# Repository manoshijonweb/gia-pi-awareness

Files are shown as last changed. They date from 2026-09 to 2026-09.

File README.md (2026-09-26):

# Gia — hardware bring-up

Raspberry Pi 5 Model B Rev 1.0, Pi OS with Python 3.13.5, `aarch64`.

Hostname `pi` (**not** `raspberrypi` — `raspberrypi.local` will not resolve).

## How to set it up

The finished device is the app in [`PI_AWARENESS/`](PI_AWARENESS/). It is an offline
assistive device for blind users that announces objects, colours, text and distance by
voice, in English and Hindi.

You need a Raspberry Pi 5 running Raspberry Pi OS 64-bit, the wired hardware listed
below, and an internet connection for the first install only.

```bash
git clone https://github.com/manoshijonweb/gia-pi-awareness.git
cd gia-pi-awareness/PI_AWARENESS
bash install.sh
sudo reboot
```

After the reboot the device says **"I am ready"** and listens for commands.

**The AI models are not in this repository.** They are too large for GitHub.
`install.sh` downloads them once from their public sources. The YOLO26 and OCR files
are checked against pinned SHA-256 hashes. The Vosk models have no published hash, so
the installer records their hashes locally and checks against those afterwards.

| Model | Used for | Downloaded from |
|---|---|---|
| YOLO26 (ONNX) | Object detection | Hugging Face (`onnx-community`) |
| PP-OCRv5 (RapidOCR) | Reading text | ModelScope (`RapidAI`) |
| Vosk small en-in, small hi | English and Hindi voice commands | alphacephei.com |

To fetch or check them again later:

```bash
.venv/bin/python tools/download_models.py           # download anything missing
.venv/bin/python tools/download_models.py --verify  # check files, no internet
```

Once installed, the device never needs the internet. Full instructions, voice
commands and troubleshooting are in [`PI_AWARENESS/README.md`](PI_AWARENESS/README.md).

The rest of this page is the original hardware bring-up log.

## Hardware

| Part | Bus | Status |
|---|---|---|
| VL53L0X time-of-flight ranger | I2C, 0x29 | verified — model `0xEE`, rev `0x10` |
| INMP441 MEMS microphone | I2S capture | verified — speech transcribed back as text |
| MAX98357A class-D amp | I2S playback | verified — 440Hz tone audible |

### Wiring

Both audio parts share BCLK and LRCLK; only the data line differs.

| Pin (BCM) | Header | VL53L0X | INMP441 | MAX98357A |
|---|---|---|---|---|
| GPIO2 | 3 | SDA | — | — |
| GPIO3 | 5 | SCL | — | — |
| GPIO18 | 12 | — | SCK | BCLK |
| GPIO19 | 35 | — | WS | LRC |
| GPIO20 | 38 | — | SD | — |
| GPIO21 | 40 | — | — | DIN |
| 3V3 | 1 / 17 | VIN | VDD | — |
| 5V | 2 / 4 | — | — | VIN |
| GND | 6 / 9 / 39 | GND | GND, L/R | GND, GND |

Three details that are easy to get wrong:

- **INMP441 `L/R` to GND.** Selects the left slot. Floating gives silence.
- **MAX98357A `VIN` to 5V**, not 3.3V. 3.3V works but is very quiet.
- **MAX98357A `SD` left floating.** Averages L+R to mono.

VL53L0X `XSHUT` floats or goes high — never low, or the chip sits in reset and
the bus scans clean.

## Boot configuration

`/boot/firmware/config.txt` (note: `/boot/firmware/`, not `/boot/`, on Pi 5).

```
dtparam=i2c_arm=on

[all]
# Gia: INMP441 (capture) + MAX98357A (playback) on one I2S bus
dtoverlay=googlevoicehat-soundcard
```

Backup of the pre-change file: `/boot/firmware/config.txt.bak-gia`.

`googlevoicehat-soundcard` is the overlay to use despite the name — it is the
generic full-duplex I2S card, and it is what puts capture *and* playback on a
single card. `hifiberry-dac` would drive the MAX98357A but leave no microphone.

`dtoverlay=nospi10` under `[pi5]` is stock Pi OS. Leave it.

After reboot, `aplay -l` and `arecord -l` both show:

```
card 2: sndrpigooglevoi [snd_rpi_googlevoicehat_soundcar]
```

Cards 0 and 1 are the Pi 5's two HDMI outputs and are unrelated.

## Scripts

One file per device. Each is a small module with a single class, and each runs
on its own as a demo. Run one to test that device; import it to build on it.

| File | Class | What it does |
|---|---|---|
| `vl53l0x.py` | `Ranger` | Distance sensing |
| `inmp441.py` | `Microphone` | Recording |
| `max98357a.py` | `Speaker` | Playback |
| `transcribe.py` | `SpeechToText` | Offline speech to text |
| `example.py` | — | All four working together |

### The whole API

```python
from vl53l0x import Ranger
from inmp441 import Microphone
from max98357a import Speaker
from transcribe import SpeechToText

ranger = Ranger()
ranger.distance()                  # mm, or None if nothing is there
ranger.wait_until_closer(600)      # blocks until someone walks up
ranger.wait_until_clear(800)       # blocks until they leave

mic = Microphone()
mic.record(5, "clip.wav")          # save a wav
mic.samples(5)                     # numpy array, DC offset removed
mic.speech_pcm(5)                  # bytes for a recogniser
mic.level()                        # 0.0 to 1.0, how loud right now

speaker = Speaker()
speaker.beep()                     # short cue tone
speaker.tone(440, 2)               # hz, seconds
speaker.play("clip.wav")

ears = SpeechToText()
ears.listen(mic, seconds=5)        # -> "what they said"
ears.transcribe(pcm)               # if you already have audio
```

### Running them directly

```
python3 vl53l0x.py       # live distance readout
python3 inmp441.py       # live level meter
python3 max98357a.py     # test tone
python3 transcribe.py    # beep, listen 5s, print what you said
python3 example.py       # wait for approach -> beep -> listen -> respond
```

### Building on them

`example.py` is the starting point — it waits for someone to approach, beeps,
listens, and responds, in about twenty lines. Replace its `respond()` function
and leave the rest.

The device quirks are handled inside the classes so nothing downstream has to
know about them: the mic's DC offset and 24-in-32-bit framing, the ranger's
out-of-range sentinel, click-free fades on generated tones. Both audio files
find the sound card **by name** from `/proc/asound/cards` rather than
hardcoding `plughw:2,0`, because that index shifts when an HDMI output comes
or goes.

`find_device()` is deliberately duplicated in `inmp441.py` and `max98357a.py`
rather than shared. Six lines of repetition keeps each file something you can
copy into another project on its own.

### Bring-up script

| Script | Does |
|---|---|
| `hwcheck.py` | Platform, I2C bus, 0x29 chip ID, ALSA card inventory |

```
pip install smbus2 adafruit-circuitpython-vl53l0x --break-system-packages
python3 hwcheck.py
python3 range_test.py
python3 audio_test.py
speaker-test -D plughw:2,0 -c 2 -t sine -f 440
```

## Known-good baselines

VL53L0X at ~11cm from a flat target:

```
109 mm, ±2 mm noise, tracking smoothly to 88 mm as the target approached
```

INMP441, 5s of normal room speech:

```
left    DC offset +2424158 (+0.11% FS)   AC rms 54823213 (2.55% FS)   LIVE
right   silent
```

Right channel silent is **correct** — `L/R` tied to GND puts the mic in the
left slot only. Record in stereo, use the left channel.

## Gotchas hit during bring-up

- The INMP441 is 24-bit in 32-bit frames. Record `S32_LE`. `S16_LE` gives noise
  or silence.
- It carries a large DC offset by design. High-pass it in software; it is not a
  wiring fault.
- VL53L0X clone boards ship with a near-invisible protective film over the lens.
  It reads "out of range" forever until peeled.
- Pi 5 `config.txt` lives at `/boot/firmware/config.txt`.
- Passing inline Python to `ssh` from PowerShell mangles the quoting. Write a
  file and `scp` it.
- Speaking directly into the INMP441 clips at 100% FS and wrecks ASR accuracy.
  Normal speech at 15–20cm lands around 15% FS, which is the target.
- `arecord -d` accepts whole seconds only. For fractional windows use `-s`
  (samples per channel) instead.
- Remote level-tests are worthless without a cue the user can perceive — the
  recording starts before they can read an instruction. `transcribe.py` plays a
  beep through the MAX98357A for exactly this reason.

## Speech to text

Vosk, offline, no API key.

```
pip install vosk --break-system-packages
wget https://alphacephei.com/vosk/models/vosk-model-small-en-us-0.15.zip
unzip vosk-model-small-en-us-0.15.zip
python3 transcribe.py --seconds 10
```

`vosk-model-small-en-us-0.15` (40MB, unpacks to 68MB) is fast but lossy — it
fills gaps with plausible English. `vosk-model-en-us-0.22` (~1.8GB) is far more
accurate and the Pi 5 can run it, more slowly.

## Where this stopped — 2026-09-22

Hardware bring-up is **complete**. All three parts verified independently on
real hardware, not just at the signal level:

- VL53L0X read 109mm ±2mm and tracked a target to 88mm
- INMP441 speech came back as readable text through Vosk
- MAX98357A played an audible 440Hz tone, and loopback playback of a live
  recording was audible

The ranger and the audio share no pins and sit on different buses, so
integration from here is a software problem, not a wiring one.

### Open issues

1. **The mic clips.** Every capture peaks at ~100% FS. Not a wiring fault, but
   flat-topped audio badly degrades speech recognition — the garbled Vosk
   transcript was partly this. Find whether it is proximity, a loud room, or
   something near the board, before building anything speech-driven.
2. **The small Vosk model is lossy.** It fills gaps with plausible English.
   `vosk-model-en-us-0.22` (~1.8GB) is far more accurate if accuracy matters.
3. ~~**No version control yet.**~~ Now on GitHub (2026-09-26).

### What Gia actually is — still undecided

A ToF ranger plus speech-in and audio-out is the shape of a machine that
notices someone approach and talks to them. The obvious next pieces would be
wake-on-approach (distance threshold starts a listen), a listening loop that
is not a fixed-length window, and the response path. That is a guess, not a
decision — the purpose has not been written down anywhere yet, and it should
be before the architecture hardens around an assumption.

### Resuming

```
ssh <user>@<pi-address>
cd ~
python3 hwcheck.py             # confirms all three are still live
```

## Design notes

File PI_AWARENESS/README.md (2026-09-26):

# PI_AWARENESS — Raspberry Pi 5 voice-first offline awareness device

Version **1.2.0** · 22 September 2026

This release is built around the **actual assembled hardware**, not generic placeholders:

- Raspberry Pi 5, Raspberry Pi OS Lite 64-bit
- Raspberry Pi Camera Rev 1.3 / Camera Module 1 on CSI, through Picamera2
- INMP441 I2S MEMS microphone
- MAX98357A I2S amplifier/speaker
- VL53L0X ToF distance sensor at I2C address `0x29`
- YOLO26m 640×640 ONNX CPU object detection
- PP-OCRv5 mobile ONNX English + Devanagari OCR
- Vosk offline English/Hindi command recognition
- eSpeak NG offline English/Hindi speech output

Normal runtime uses **no internet**. Installation needs internet once to install packages and download model weights.

> This is an experimental information aid, not a replacement for a white cane, guide dog,
> orientation-and-mobility training, or a human helper. A missed object or failed distance reading
> must never be interpreted as a clear path.

## What happens after boot

`install.sh` installs and **enables `pi-awareness.service` automatically**. After the next reboot,
the service loads its offline speech models and detector, speaks exactly:

> **I am ready**

and then listens for voice commands.

The service is power-aware while idle:

- the INMP441 capture stream stays active so voice commands can be heard;
- only a lightweight RMS/VAD path runs on silent audio;
- Vosk receives audio only after speech crosses the VAD threshold;
- the CSI camera is **not continuously streaming**;
- VL53L0X is **not continuously polled**;
- YOLO/OCR inference runs only when requested;
- YOLO26m is warmed once at boot to avoid first-scan graph startup latency, then consumes no detector CPU while idle.

This is not hardware deep sleep: a device that must hear speech continuously cannot power off the CPU and microphone.
Raspberry Pi OS is left free to perform its normal CPU frequency scaling while the service is idle.

## Voice commands

| English | Hindi | Action |
|---|---|---|
| `scan`, `what is this?`, `what is in front of me?` | `देखो`, `यह क्या है`, `मेरे सामने क्या है` | Capture one frame and announce detected object counts |
| `color`, `what color?` | `रंग`, `रंग बताओ` | Capture one frame and announce the central dominant color |
| `read`, `read text` | `पढ़ो`, `क्या लिखा है` | Capture one frame, OCR it, and speak the text |
| `distance`, `how far?` | `दूरी`, `दूरी बताओ` | Take an on-demand VL53L0X reading and report calibrated steps |
| `repeat` | `दोहराओ` | Repeat the last result |
| `stop` | `रुको` | Stop the current spoken/processing response where supported |
| `calibrate` | `कदम नापो` | Start step-length calibration |
| `speak hindi` / `speak english` | `हिंदी में बोलो` / `अंग्रेजी में बोलो` | Change response language |

### Object counts

`scan` counts detections by COCO class. Example:

```text
I see 2 people, 1 chair, and 1 bottle.
```

The model still recognises the standard 80 COCO categories; it does not identify arbitrary product identities.

## Exact hardware profile

### INMP441 microphone

The supplied hardware helper established this wiring and capture contract:

| INMP441 | Pi 5 |
|---|---|
| SCK / BCLK | physical pin 12 / GPIO18 |
| WS / LRCLK | physical pin 35 / GPIO19 |
| SD / DOUT | physical pin 38 / GPIO20 |
| VDD | 3.3 V |
| GND | GND |
| L/R | **GND** |

The repo captures it as **S32_LE, 48 kHz, 2-channel-framed I2S**, selects the left channel,
removes DC offset, averages 48 kHz → 16 kHz, applies configurable gain, and feeds 16-bit PCM to Vosk.

### MAX98357A speaker amplifier

| MAX98357A | Pi 5 |
|---|---|
| BCLK | physical pin 12 / GPIO18 |
| LRC | physical pin 35 / GPIO19 |
| DIN | physical pin 40 / GPIO21 |
| VIN | 5 V |
| GND | GND |
| SD | float/high |

INMP441 and MAX98357A share BCLK/LRCLK. The install script enables the single
`googlevoicehat-soundcard` overlay used by the supplied hardware test. Card numbers are discovered by
name at runtime; they are not hard-coded.

### VL53L0X

| VL53L0X | Pi 5 |
|---|---|
| SDA | physical pin 3 |
| SCL | physical pin 5 |
| VIN | 3.3 V |
| GND | GND |
| XSHUT | float/high |

The actual supplied VL53L0X helper treats about **30–1200 mm** as the useful configured range.
This is intentionally different from the older repo's VL53L1X/4 m assumption.

### Raspberry Pi Camera Rev 1.3

The repo selects `picamera2`, camera index `0`, 1280×960 capture, and no autofocus. The Rev 1.3 /
Camera Module 1 hardware is fixed-focus. Each vision command opens the camera, obtains a fresh frame,
and closes it again.

## Fresh installation on the Pi

Copy/extract the ZIP onto the Pi and run:

```bash
cd ~/PI_AWARENESS
bash install.sh
sudo reboot
```

`install.sh`:

1. verifies Raspberry Pi 5 + 64-bit OS;
2. installs Pi camera/audio/I2C packages;
3. enables I2C and I2S;
4. adds `dtoverlay=googlevoicehat-soundcard` and `camera_auto_detect=1` if missing;
5. creates `.venv`;
6. installs the pinned runtime dependencies;
7. downloads the detector/OCR/Vosk assets once;
8. runs software/model diagnostics;
9. installs and enables `pi-awareness.service`.

The service is intentionally not started before the reboot because Device Tree and group changes may not yet be active.

## Service operation

```bash
sudo systemctl status pi-awareness
journalctl -u pi-awareness -f
sudo systemctl restart pi-awareness
sudo systemctl disable --now pi-awareness
```

The service has a private network namespace, so the application process cannot use the internet during normal operation.
SSH/networking for the rest of the Pi is not disabled.

## Hardware test after installation

The service owns the I2S microphone. Stop it before exclusive hardware diagnostics:

```bash
cd ~/PI_AWARENESS
sudo systemctl stop pi-awareness

.venv/bin/python tools/hwcheck.py
.venv/bin/python tools/mic_test.py --seconds 15
.venv/bin/python tools/speaker_test.py
.venv/bin/python server.py --doctor --deep --hardware

sudo systemctl start pi-awareness
```

The hardware check tests the shared I2S card, microphone signal, speaker beep, camera frame and VL53L0X response.

## Manual application test

Stop the service first, then:

```bash
sudo systemctl stop pi-awareness
source .venv/bin/activate
python server.py
```

Press `Ctrl+C`, then restart the service:

```bash
sudo systemctl start pi-awareness
```

For typed commands without the microphone:

```bash
python server.py --text --no-speech
```

For a specific local image:

```bash
python server.py --image /path/test.jpg --once scan --no-speech
python server.py --image /path/test.jpg --once read --no-speech
python server.py --image /path/test.jpg --once color --no-speech
```

## Tune the microphone

Default INMP441 conversion settings are:

```python
CONFIG.voice.i2s_gain = 10.0
CONFIG.voice.rms_threshold = 180.0
```

Run `tools/mic_test.py` in a quiet room. Quiet blocks should stay below the threshold and normal speech should rise clearly above it.
Do not lower the threshold until silence/noise values are known.

## Step calibration

With a helper, walk a measured safe distance and count individual steps. Example: 10 steps over 6500 mm:

```bash
.venv/bin/python server.py --calibrate-distance-mm 6500 --steps 10
```

That saves 650 mm/step. The distance sensor measures from the sensor position, not from the user's toes.

## Power/latency trade-off

Default choices intentionally balance idle power and response speed:

- camera: on-demand and closed immediately after capture;
- VL53L0X: on-demand, one approximately 200 ms reading per distance query;
- YOLO26m: graph warmed at service start and retained in RAM;
- OCR: loaded on first `read` command and retained afterward;
- two small Vosk models: resident so English/Hindi commands remain immediately available.

Set `CONFIG.power.preload_detector=False` to minimize boot work/RAM, but the first `scan` will be slower.
A true ultra-low-power standby that wakes the Pi from speech would require separate always-on wake-word hardware or a lower-power coprocessor.

## Repository map

```text
server.py                 entry point
settings.py               assembled-hardware configuration
install.sh                Pi provisioning + service enable
run.sh                    manual launcher
awareness/                voice, camera, vision, OCR, color, distance, TTS
hardware/                 INMP441, MAX98357A, VL53L0X and I2S helpers
hardware/hwcheck_original.py  original supplied hardware sanity-check retained for reference
tools/hwcheck.py          integrated hardware test
tools/install_service.sh  systemd unit installer
tools/mic_test.py         live INMP441 RMS/VAD tuning
tools/speaker_test.py     bilingual speaker test
tools/benchmark.py        feature timing measurements
tests/                    software/mocked-hardware tests
models/                   populated by install.sh
state/                    step calibration / installation state
logs/                     rotating runtime logs
```

See `docs/HARDWARE.md`, `docs/ACCEPTANCE.md`, and `TEST_REPORT.md` before a supervised user trial.

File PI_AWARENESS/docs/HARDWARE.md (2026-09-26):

# Hardware — assembled Pi 5 profile

This release is not a generic pinout. It implements the hardware supplied for this build.

## I2S audio

Both audio devices share GPIO18/GPIO19 clocks and use different data directions:

```text
Pi 5 GPIO18 / pin 12  -> INMP441 SCK  + MAX98357A BCLK
Pi 5 GPIO19 / pin 35  -> INMP441 WS   + MAX98357A LRC
Pi 5 GPIO20 / pin 38  <- INMP441 SD
Pi 5 GPIO21 / pin 40  -> MAX98357A DIN
3V3                    -> INMP441 VDD
5V                     -> MAX98357A VIN
GND                    -> both grounds
INMP441 L/R            -> GND
MAX98357A SD            -> float/high
```

The installer adds:

```text
dtparam=i2s=on
dtoverlay=googlevoicehat-soundcard
```

The runtime locates `sndrpigooglevoi` in `/proc/asound/cards` and uses `plughw:<card>,0`.
This prevents HDMI insertion/removal from breaking a hard-coded ALSA card number.

INMP441 capture is S32_LE, 48 kHz, 2-channel framed; only the left channel carries the mic because L/R is tied low.

## VL53L0X

```text
pin 3  / SDA -> SDA
pin 5  / SCL -> SCL
3V3          -> VIN
GND          -> GND
XSHUT        -> float/high
```

I2C address: `0x29`. The supplied helper uses a 200,000 µs measurement timing budget and treats 8190 as no-return.
The service does not poll the sensor while idle; the `distance` command opens it on demand.

## Camera Rev 1.3

Use the correct Pi 5 camera ribbon/cable orientation. The software uses Picamera2 and camera index 0.
Camera Rev 1.3 / Camera Module 1 is fixed-focus, so autofocus is disabled in `settings.py`.
The camera is not streamed in idle mode.

## Power

Software idle mode eliminates camera streaming, detector/OCR inference and ToF polling. The microphone, ALSA capture,
VAD and resident speech recognizers remain active because the device must hear commands. This is not deep sleep.

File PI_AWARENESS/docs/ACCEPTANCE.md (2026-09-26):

# Acceptance checklist

Run tests on the assembled Raspberry Pi 5, not only on a desktop.

1. Install and reboot. Confirm the service starts and says exactly **"I am ready"** once.
2. Leave it idle for at least 10 minutes. Confirm no camera streaming process and no continuous VL53L0X polling.
3. In a quiet room, confirm microphone noise stays below the configured VAD threshold and normal speech rises above it.
4. Test all English commands: scan, color, read, distance, repeat, stop.
5. Test the Hindi equivalents.
6. Put two people/chairs or repeated COCO objects in view and confirm `scan` announces counts rather than only unique class names.
7. Test 20 varied object scenes and record missed/duplicate detections.
8. Test OCR on English, Hindi and mixed-script samples under normal lighting.
9. Test color under daylight and indoor lighting; it is a descriptive classifier, not a colorimeter.
10. Measure the VL53L0X against known distances in its configured ~30–1200 mm range. Invalid/no-return must never be announced as clear.
11. Calibrate the user's step length and repeat distance tests.
12. Measure full command-to-first-meaningful-audio latency, not just ONNX inference time.
13. Run sustained use while monitoring `vcgencmd measure_temp` and `vcgencmd get_throttled`.
14. Disconnect network access and confirm scan/color/read/distance/voice continue to operate.

This prototype must not be accepted as a sole navigation or hazard-avoidance system.

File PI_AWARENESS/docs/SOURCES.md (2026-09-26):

# Sources and provenance

Primary external references used by this release:

- Raspberry Pi camera software / Picamera2:
  https://www.raspberrypi.com/documentation/computers/camera_software.html
- Raspberry Pi camera modules, including Camera Module 1:
  https://www.raspberrypi.com/documentation/accessories/camera.html
- Raspberry Pi Device Tree overlays and `googlevoicehat-soundcard`:
  https://github.com/raspberrypi/firmware/blob/master/boot/overlays/README
- Adafruit CircuitPython VL53L0X package:
  https://pypi.org/project/adafruit-circuitpython-vl53l0x/
- Ultralytics detection documentation:
  https://docs.ultralytics.com/tasks/detect/
- Ultralytics Raspberry Pi guide:
  https://docs.ultralytics.com/guides/raspberry-pi/
- ONNX Community YOLO26m conversion:
  https://huggingface.co/onnx-community/yolo26m-ONNX
- Vosk model catalogue:
  https://alphacephei.com/vosk/models
- RapidOCR model catalogue:
  https://rapidai.github.io/RapidOCRDocs/main/model_list/

The four hardware helper files supplied with this task are the basis for the assembled pinout and low-level device contracts.
The original `hwcheck.py` is retained as `hardware/hwcheck_original.py` for traceability.

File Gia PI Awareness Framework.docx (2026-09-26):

PI AWARENESS PROJECT WRITE-UP WORKBOOK

USP, RESEARCH FRAMEWORK, ALGORITHM, AND PROJECT EVIDENCE

Use this workbook to prepare the final project report. Write in your own words. Add dates, screenshots, test results, and personal observations wherever a blank is provided. Do not claim results that were not actually measured.

PROJECT DETAILS

Project title: PI Awareness - A Talking Device That Tells Blind People What Is in Front of Them

Student name: Gia Gupta

Class / section:

School / institution:

Project guide:

Start date: Completion date:

One-line description of my project:

I built a small Raspberry Pi 5 device that listens to a spoken command and then tells a blind or low-vision person, through audio, what objects are in front of them, what colour an object is, what text is written on it, and how many steps away an obstacle is. It works without the internet.

My intended users are:

People who are blind or have low vision, especially people in India who speak Hindi or English, and the family members, teachers and helpers who support them.

1. PROJECT TITLE

What to cover:

Write the final name of the project and a short subtitle that explains what it does.

Pointer for PI Awareness:

The title may mention assistive technology, blind or low-vision users, object detection, colour identification, text reading, audio feedback, or offline operation.

Final title:

PI Awareness: An Offline, Voice-Controlled Device That Tells Blind People What Object Is in Front of Them, Its Colour, and the Text Written on It - Through Audio

Why I selected this title:

I called it "PI" because my device is built on a Raspberry Pi, and "Awareness" because that is what I want it to give the user: awareness of the things around them that they cannot see. I added a subtitle that names the three questions my device answers (what is it, what colour is it, what does it say), who it is for, and that the answer comes as sound, so anyone reading the title understands my project straight away.

2. STUDENT NAME

What to cover:

Write the student's full name and school details exactly as required by the competition or school.

Student name: Gia Gupta

Class / section:

Roll number:

School:

Guide / teacher:

3. ABSTRACT - OPTIONAL FOR PRODUCT DEVELOPMENT PROJECTS

What to cover:

Write 100-150 words covering the problem, product, main technology, result, and future use.

Pointers to include:

- PI Awareness helps blind and low-vision people know what is in front of them.

- The user gives a spoken command; the INMP441 microphone and Vosk recognise it offline.

- The camera takes one photo only when a command is given.

- YOLO26 detects objects, a colour algorithm names the colour, and PP-OCRv5 reads text.

- The answer is spoken aloud through the MAX98357A speaker in English or Hindi.

- Mention that it is an information aid, not a replacement for a white cane or guide dog.

Draft abstract:

Blind and low-vision people often cannot tell what object is in front of them, what colour it is, or what a label says without asking someone for help. I built PI Awareness, a small device on a Raspberry Pi 5 that answers these questions through audio. The user speaks a command in English or Hindi. My device takes one photo and uses offline AI models to detect and count objects (YOLO26), name the main colour in the centre, or read printed text (PP-OCRv5). A distance sensor tells how many steps away an obstacle is. The answer is spoken through a small speaker, and everything works without the internet. In 152 tests I logged on the device, object, colour and text answers were ready about 2 to 2.5 seconds after I stopped speaking. My device is an information aid, not a replacement for a white cane or guide dog.

Word count: 148

4. INTRODUCTION

What to cover:

Explain the problem, who experiences it, why it matters, and why this project was selected.

Answer these questions:

1. What difficulty do blind or low-vision people face in knowing what is around them?

They cannot see which object is in front of them, what colour their clothes or things are, or what is printed on labels, medicine strips, signs and books. Most of the time they have to ask someone else, which takes away their independence, and help is not always there when they need it.

2. Why is immediate spoken feedback useful?

Someone who cannot see a screen needs the answer as sound, and straight away, while they are still holding or facing the object. A quick spoken answer means they can act on it immediately, and ask again if they are not sure.

3. Who are the intended users?

Blind and low-vision people, especially Hindi and English speakers in India, and the people who help them.

4. Why did I choose this problem?

I noticed that most apps that do this need a smartphone, a touch screen and an internet connection. I wanted to build something simpler: a device that works only by voice, speaks Hindi as well as English, and works anywhere without the internet, so it stays private and does not depend on network signal.

5. What does the current project do?

When the user gives a spoken command, my device detects and counts objects, names the main colour in the centre of the view, reads printed text aloud, and tells the distance to an obstacle in the user's own steps.

Introduction paragraph:

People who are blind or have low vision face everyday problems that sighted people hardly think about, like finding the right object on a table, picking clothes of the right colour, or reading the name on a medicine packet. Usually they have to depend on another person. For my project I built PI Awareness, a small voice-controlled device on a Raspberry Pi 5 that answers these questions through audio. The user just says "scan", "colour", "read" or "distance" (or the Hindi words dekho, rang, padho or doori), and my device looks through its camera or distance sensor and speaks the answer. Everything is processed on the device itself, so it works without the internet and no photos or recordings ever leave it.

5. BACKGROUND RESEARCH

What to cover:

Summarize the existing ideas, tools, and research that support the project. Explain what you learned from each source and cite it in the references section.

Research pointer A - Object detection:

What is object detection? How does YOLO help this project?

Source used: Ultralytics (n.d.), Object Detection documentation; Redmon et al. (2016).

What I learned:

I learned that object detection finds where objects are in a photo and names them in one step. YOLO ("You Only Look Once") models look at the whole image only once, which makes them fast enough to run on a small computer like the Raspberry Pi. The YOLO26 models I used were trained on the COCO dataset, so they can recognise 80 everyday types of object such as a person, chair, bottle, cup and book.

Research pointer B - Offline speech recognition and speech output:

How can a device understand and answer voice commands without the internet?

Source used: Alpha Cephei (n.d.), Vosk models; Povey et al. (2011).

What I learned:

I learned that Vosk is an offline speech recogniser based on the Kaldi toolkit. Its small models (about 40-70 MB) can run on a Raspberry Pi, and there are separate models for Indian English and Hindi. I also found that limiting the recogniser to a short list of command phrases makes it much more reliable. For speaking the answers, I used eSpeak NG, which turns text into speech offline in both languages.

Research pointer C - Reading text and naming colours:

How can a camera photo be turned into readable text and a colour name?

Source used: RapidAI (n.d.), RapidOCR model list; Du et al. (2020).

What I learned:

I learned that reading text from a photo (OCR) happens in two steps: first finding where the text is, and then recognising the letters in each line. The PP-OCRv5 mobile models are small enough for the Pi, and the Devanagari model can read both Hindi and English. For colour, I learned that the HSV colour space (hue, saturation, brightness) matches the way people name colours better than plain red-green-blue values, and that room lighting can change how a colour looks.

Research pointer D - Safety and privacy of camera and microphone use:

What are the safety considerations of an always-listening microphone, a camera, and giving information to a blind user?

Source used: Raspberry Pi Ltd (n.d.), Camera software documentation; World Health Organization (2019).

What I learned:

I realised that a device which is always listening and has a camera must keep what it hears and sees private, so I made my device process everything on the Pi and never save photos or recordings. The most important safety point I learned is that a missed object or a failed reading must never be taken to mean "the path is clear". My device is an extra aid and does not replace a white cane, a guide dog, or mobility training.

In-text citations I will use:

(Redmon et al., 2016); (Ultralytics, n.d.); (Lin et al., 2014); (Povey et al., 2011); (Alpha Cephei, n.d.); (Du et al., 2020); (RapidAI, n.d.); (Raspberry Pi Ltd, n.d.); (World Health Organization, 2019)

6. HYPOTHESIS

What to cover:

Write a statement that can be tested. Use an "If..., then..." format.

Main hypothesis:

If a Raspberry Pi 5 device with a camera, a microphone, a speaker and offline AI models is given a spoken command in English or Hindi,

then it will speak back the objects, the main colour, or the printed text in front of the camera, with the result ready within 5 seconds of the user finishing speaking, without any internet connection.

Secondary hypothesis about on-demand (power-saving) operation:

If the camera and distance sensor are switched on only when a command is given and switched off straight after,

then my device will still answer quickly, while doing no camera or AI work when it is idle.

What evidence would support my hypothesis?

The device log showing every scan, colour and read result ready in under 5 seconds, the camera opening and closing once for each command, and my device giving correct answers for real objects and text.

What evidence would not support my hypothesis?

Results taking longer than 5 seconds, commands not being recognised, the camera staying on while idle, wrong answers for common objects, or any feature needing the internet.

7. GOAL OF THE STUDY

What to cover:

State the main objective and list measurable smaller objectives.

Main goal:

My main goal was to build a low-cost, voice-controlled device that works without the internet and tells a blind or low-vision person, through audio, what object is in front of them, what colour it is, and what text is written on it.

Objectives checklist:

[x] Listen for voice commands in English and Hindi without the internet.

[x] Take a camera photo only when a command is given.

[x] Detect objects and speak how many of each type are seen.

[x] Identify and speak the main colour in the centre of the view.

[x] Read printed English and Hindi text aloud.

[x] Measure the distance to an obstacle and report it in the user's steps.

[x] Speak every answer through a speaker, and let the user repeat or stop it.

[x] Start automatically when switched on and say "I am ready".

[x] Fit all the parts into a 3D-printed casing.

[ ] Test the device with blind or low-vision users.

My additional objective:

I also wanted my device to be power-aware: the camera and distance sensor stay off and no AI model runs while it is waiting for a command.

8. MATERIALS

What to cover:

List hardware, software, services, data, and other materials actually used.

Hardware used:

Material / device | Available? | Purpose
Raspberry Pi 5 Model B | Yes | Main computer; runs all the AI models on the device
Raspberry Pi Camera Rev 1.3 | Yes | Takes one photo when scan, colour or read is asked
INMP441 I2S MEMS microphone | Yes | Hears the user's voice commands
MAX98357A amplifier and speaker | Yes | Speaks the answers aloud
VL53L0X time-of-flight sensor | Yes | Measures distance to an obstacle (about 30-1200 mm)
32 GB microSD card | Yes | Stores the operating system, code and AI models
5 V power supply | Yes | Powers the Raspberry Pi and all parts
Jumper wires | Yes | Connect the sensors and audio parts to the Pi's GPIO pins
3D-printed casing (box, top, speaker cover) | Yes | Holds and protects all the parts
Laptop | Yes | Writing code, connecting to the Pi over SSH, designing the casing
Internet connection | Setup only | Downloading packages and models once; not used when running

Software and services used:

Tool / library | Purpose
Raspberry Pi OS (64-bit) and Python 3.13 | Operating system and programming language
Vosk (small Indian-English and Hindi models) | Offline speech recognition of voice commands
eSpeak NG | Offline text-to-speech in English and Hindi
YOLO26 (ONNX) | Object detection for 80 everyday object types
PP-OCRv5 mobile (RapidOCR ONNX models) | Finding and reading printed English and Hindi text
ONNX Runtime | Runs the YOLO and OCR models on the Pi's processor
OpenCV and NumPy | Image processing and colour calculations
Picamera2 | Controls the Raspberry Pi camera
ALSA (arecord / aplay), googlevoicehat overlay | Sound input from the microphone and output to the speaker
adafruit-circuitpython-vl53l0x, smbus2 | Reading the distance sensor over I2C
systemd service | Starts my program automatically when the Pi is switched on
Autodesk Inventor | Designing the 3D-printed casing

Other materials or data:

I used pre-trained models only (YOLO26 trained on the COCO dataset of 80 object types, PP-OCRv5 Devanagari text models, and Vosk speech models). I did not collect a new dataset.

9. METHOD

What to cover:

Describe how the product was planned, built, and tested. Add dates or screenshots where possible.

A. Product-building steps

Step | What I did | Date
1 | Identified the problem and users
2 | Chose the hardware and planned the voice commands
3 | Built my first offline prototype: voice, colour, text, objects, distance (v1.0.0)
4 | Made YOLO26m the default object detector (v1.1.0) | 16 Sep 2026
5 | Wired and tested the VL53L0X, INMP441 and MAX98357A on the Pi 5 | 21-22 Sep 2026
6 | Enabled I2C and the I2S sound card in the Pi's boot configuration | 21-22 Sep 2026
7 | Rebuilt the software around my assembled hardware (v1.2.0) | 22 Sep 2026
8 | Made the camera and distance sensor work only on demand | 22 Sep 2026
9 | Added auto-start at boot with the "I am ready" announcement | 22 Sep 2026
10 | Designed and 3D-printed the casing (up to version 4) | by 24 Sep 2026
11 | Tested the voice commands on the device and recorded response times | 22-25 Sep 2026
12 | Ran the software self-test on the Pi and wrote up the results | 25 Sep 2026

B. User workflow

Number the actual workflow in your own words:

1. The user switches the device on. It starts by itself, loads its models, and says "I am ready".

2. The user points the device towards the object, label or direction they want to know about.

3. The user says a command: "scan", "colour", "read" or "distance" (or dekho, rang, padho, doori).

4. The microphone hears the speech, and Vosk recognises the command on the device.

5. The camera switches on, takes one photo, and switches off (or the distance sensor takes one reading).

6. The AI model finds the objects, the main colour, the text, or the distance.

7. The result is turned into a short sentence in the user's language and spoken through the speaker.

8. The user can say "repeat" or "stop", change the language, or give the next command.

C. Algorithm: voice command recognition

What to cover:

Explain the algorithm in simple steps and include the formula.

1. How is the audio received and prepared?

The INMP441 sends 24-bit sound inside 32-bit frames at 48,000 samples per second. My program keeps the left channel, removes the DC offset, averages every 3 samples to get 16,000 samples per second, and multiplies by a gain of 10. It does this in blocks of 50 ms.

2. How is speech detected?

For every 50 ms block my program calculates the loudness (RMS). If it is 3500 or more, the block counts as speech. Speech ends after 0.5 s of quiet; sounds shorter than 0.15 s are ignored, and one command can be at most 7 s long.

3. How does Vosk process the audio?

Only the speech part is sent to two offline Vosk models, one for Indian English and one for Hindi. I limited each model to my list of command phrases, so a random sentence can never turn into an action.

4. How is the recognised text normalised?

The text is changed to lower case, punctuation and extra spaces are removed, and an optional "hello" or "suno" at the start is dropped. Hindi letters and marks are kept as they are.

5. Which comparison method is used?

The cleaned text has to exactly match a phrase in my command table, and the recogniser's confidence has to be at least 0.58. If the English and Hindi models suggest different commands with confidences less than 0.10 apart, my device does nothing.

Current formulas:

loudness (RMS) = square root of (average of each sample squared); a block is speech if RMS >= 3500

command accepted if: exact phrase match AND confidence >= 0.58 AND (best - second best) >= 0.10 when the two languages disagree

Explain the formula in your own words:

My device only starts listening properly when the sound is loud enough to be speech, which saves work while the room is quiet. Then it only acts when it is fairly sure it heard one of its exact command words, and when the English and Hindi guesses clearly agree on which command it was.

Important limitation to mention:

Only fixed command phrases are understood. The confidence scores of the two language models are not true probabilities, loud background noise can trigger the speech detector, and I have to tune the threshold for each room and microphone.

D. Algorithm: object detection and counting

What to cover:

Explain that this runs only when the user says "scan", on the device, without the internet.

Steps used:

[x] Take one camera photo at 1280 x 960 pixels, then close the camera.

[x] Resize the photo to 640 x 640 and scale the colours to between 0 and 1.

[x] YOLO26 gives a box and 80 class scores for each possible object.

[x] Turn each best score into a probability and keep only objects at or above 0.40.

[x] Count the objects of each type and speak up to 8 types, most confident first.

Current formula:

object score = 1 / (1 + e-logit); keep the object if score >= 0.40

spoken sentence = "I see " + count and name of each type, e.g. "I see 2 people, 1 chair, and 1 bottle."

Why should this result be described as approximate?

The model only knows 80 COCO object types, and it can miss objects that are small, dark, far away or partly hidden. My camera is fixed-focus, so very close objects can be blurry. If nothing is found, my device says "No familiar objects detected. This does not mean the area is clear."

What camera data is saved or sent anywhere, if any?

None. The photo stays in memory only while it is being processed. It is not saved to the card, and my program cannot use the internet.

E. Algorithm: colour identification

What to cover:

Explain how the device decides the main colour of the object in the centre of the view.

Steps used:

[x] Correct the lighting using grey or white areas in the whole photo (gain limited to 0.85-1.18).

[x] Cut out the central 45% of the photo and shrink it to 80 x 80 pixels.

[x] Convert to HSV, treating hue as a circle so that the two ends of red count as close.

[x] Group the pixels into 3 colour groups with k-means clustering.

[x] Name each group (12 colours, with "dark" or "light") and pick the largest.

Current formula:

dominance = pixels of the winning colour / all pixels in the centre; the colour is spoken if dominance >= 0.50

If the median brightness is below 22, my device says it is too dark to identify the colour.

Explain the formula in your own words:

My device only names a colour when at least half of the centre of the picture is that colour. If the centre is mixed, it asks the user to hold the object closer instead of guessing.

F. Algorithm: text reading

What to cover:

Explain how the photo is turned into spoken text.

Steps used:

[x] The text detector finds areas that look like text (photo resized to at most 736 pixels).

[x] Each area is cut out, straightened, and turned the right way up if it is upside down.

[x] The recogniser reads the letters in each line (English and Hindi).

[x] Lines are put in reading order, top to bottom and left to right.

[x] Reading stops after 80 lines or 8 seconds so the user is not kept waiting.

Current formula:

line confidence = average of the highest letter probability at each position; the line is spoken if confidence >= 0.62

Explain the formula in your own words:

A line is only read aloud when the model is fairly sure about its letters. If some lines are unclear, my device reads the clear ones and then tells the user that some text could not be read, so they can move closer.

G. Algorithm: distance and steps

What to cover:

Explain how the application turns a distance reading into information the user can act on.

The program calculates:

[x] One fresh distance reading of about 200 ms, only when asked

[x] Whether the reading is valid (30-1200 mm and less than 1 second old)

[x] Distance in the user's own steps

[x] A caution message when the object is less than one step away

[x] Step length from a measured walk during calibration

Current steps formula:

steps = floor(2 x distance in mm / step length in mm) / 2

Current calibration formula:

step length = measured walking distance / number of steps counted (allowed range 200-1200 mm; default 750 mm)

How does the safety rule work?

I made the number of steps always round down to the nearest half step, so an obstacle never sounds further away than it really is. If the sensor gives no valid reading, my device says "Distance unavailable. Do not assume the path is clear."

H. Evidence of method

Screenshots, photos or diagrams to attach:

[ ] Photo of the complete device in its casing

[ ] Photo of the wiring to the Raspberry Pi

[ ] 3D design of the casing (box, top, speaker cover)

[ ] Terminal showing the service running

[ ] Device log showing response times

[ ] Self-test result on the Pi

[ ] Algorithm flowchart

[ ] Data-flow diagram: microphone -> command -> camera / sensor -> model -> speaker

Screenshot / diagram number: Caption:

What this evidence proves:

10. ETHICAL ISSUES AND SAFETY CONSIDERATIONS

What to cover:

Explain how the project protects users, privacy, security, and fair interpretation of results.

Complete the table:

Issue | How PI Awareness addresses it
Microphone (always listening) | Sound is processed only on my device. Quiet sound is ignored, and audio is never saved or sent anywhere. Only the recognised command words are written to the device log, and I can switch this off.
Camera | It switches on only when the user says scan, colour or read, takes one photo, and switches off again. Photos are not saved to the card or sent anywhere.
Internet and data | My program runs in a private network space, so it cannot use the internet. The models are downloaded once during setup and checked with checksums.
User's physical safety | I describe my device as an information aid, not a replacement for a white cane, guide dog or mobility training. "No objects detected" is always followed by "this does not mean the area is clear".
Distance sensor errors | Invalid or out-of-range readings are reported as "Distance unavailable. Do not assume the path is clear." Steps are rounded down, never up.
Wrong or missed results | It only knows 80 object types; colour is a description, not an exact measurement; and it tells the user when text could not be read.
Accidental commands | Only exact command phrases cause an action; unclear speech is ignored.
Consent for user testing | Any trial with blind or low-vision people needs their informed consent (from a guardian for minors), a supervisor, and a safe indoor space.
Language and accessibility | It is fully voice-controlled with no screen needed, and works in English and Hindi. I still need to test it with different accents.
Electrical safety and heat | It uses only low-voltage (5 V) parts inside a closed 3D-printed case. I still need to measure how hot it gets during long use.

Safety statement in my own words:

I designed PI Awareness to give blind and low-vision people extra information, not to guide them safely on its own. It never tells the user that a path is clear, and it clearly says when it is unsure or when a reading has failed. Everything it hears and sees stays on the device: no photos or recordings are saved, and my program cannot connect to the internet. Before real users try it, I must test it under supervision and with their consent.

11. RESULTS AND DISCUSSION

What to cover:

Record actual testing results. Separate results observed by you from claims that still need a user study.

A. Technical test results

Test | Expected result | Actual result | Pass / fail
Software self-test on the Pi (25 Sep 2026) | All 153 tests pass | 152 passed, 1 failed: the test expects YOLO26m as default, but my settings now use YOLO26s | Fail (settings mismatch)
Distance sensor check (22 Sep 2026) | Reads a target | 109 mm, +/-2 mm noise; tracked the target to 88 mm | Pass
Microphone check (22 Sep 2026) | Speech is captured | Speech came back as text, but loud speech clipped near 100% | Pass (clipping noted)
Speaker check (22 Sep 2026) | Tone is audible | 440 Hz tone audible | Pass
Starts automatically at boot | Service running | 19 starts in the log; service "active" on 25 Sep 2026 | Pass
Voice commands recognised | English and Hindi commands | e.g. "scan", "colour", "read text", Hindi "scan" recognised in the log | Pass
Camera only on command | Opens and closes once per command | 151 opens, 149 closes; 2 failed to start | Pass (2 errors)
Scan response time | Under 5 s | Median 2.44 s, max 4.69 s (83 scans) | Pass
Colour response time | Under 5 s | Median 1.96 s, max 2.18 s (40 tests) | Pass
Read response time | Under 5 s | Median 2.44 s, max 3.87 s (29 tests) | Pass
Distance response time | Under 5 s | Median 0.82 s, max 0.94 s (14 tests) | Pass
Works with internet disconnected | All features work | Not tested on the device yet | Not tested
Correctness of spoken answers | Right objects, colours, text | Not recorded in the log | Not tested

Response time is measured by my program from the end of the user's speech until the answer is ready to be spoken. It is not the time until the sound is actually heard.

B. Device test data

Number of commands logged: 188 (152 of them scan, colour, read and distance)

Number of users tested:

Testing dates: 22-25 September 2026

Command | Times used | Median time | Notes
scan (objects) | 83 | 2.44 s | 4 failed: 2 because of a typing mistake I made in the settings, 2 when the camera did not start
colour | 40 | 1.96 s | No failures logged
read (text) | 29 | 2.44 s | Slowest single read was 3.87 s
distance | 14 | 0.82 s | I have not saved a step calibration yet, so the default 750 mm step was used
repeat, language, help, cancel | 22 | 0.55 s | No camera or model needed

C. Discussion prompts

What worked well?

All four main features worked on my real device, in both English and Hindi. Every answer was ready in under 5 seconds, and colour and distance were the fastest. The camera opened only when I gave a command and closed afterwards, and the device started by itself every time I switched it on.

What problems or errors did I observe?

The microphone clips when someone speaks loudly or too close to it, and it often picked up noise that was not a command (about 1,580 empty recognitions in the log, which were correctly ignored). On 22 Sep the microphone stream stopped twice and the camera failed to start twice. A typing mistake I made in the settings stopped scan from working for a short time, and 3 commands were dropped because the device was still busy. The English voice fell back to a British accent, and one self-test now fails because I changed the settings.

Did the results support my hypothesis? Explain.

Partly. The timing part is supported: I logged 152 commands and the slowest result was ready in 4.69 s, which is under my 5-second target. My on-demand camera hypothesis is also supported by the camera log. But I did not record whether each answer was correct, and I have not yet tested the device with the internet disconnected, so those parts are not proven yet.

What results still need a proper user study?

How accurate the answers are for real objects, colours and text; whether blind users find it useful and easy to aim; how well it hears commands in noisy places and with different accents; and battery life and heat during long use.

12. CONCLUSION

What to cover:

State what was built, whether the goal was achieved, the main limitation, applications, and future scope.

Was the main goal achieved? Yes / No / Partly

Evidence for my answer:

I built the device and it works on the real hardware: all four features ran 152 times on the Pi between 22 and 25 September 2026, and every result was ready in under 5 seconds. I say "partly" because I have not measured whether the answers are correct, and blind or low-vision users have not tested it yet.

My conclusion:

I built PI Awareness, a small device based on a Raspberry Pi 5 that listens for spoken commands in English or Hindi and tells the user, through audio, what objects are in front of them, the main colour, the printed text, and the distance to an obstacle in steps. It works completely offline and does not save any photos or recordings. On my device, answers were ready in about 2 to 2.5 seconds. Its main limitations are that it only knows 80 object types, its colour and text reading depend on good lighting, and the microphone still needs tuning. My next step is a supervised study with real users to find out how accurate and useful it really is.

Applications:

[x] Identifying everyday objects at home

[x] Reading labels, medicine packets, books and signs

[x] Checking the colour of clothes and belongings

[x] Warning about a nearby obstacle

[x] Supervised use in schools for visually impaired students

Other:

Future improvements:

[x] Recognise more object types and say where they are (left, right, centre)

[x] Fix microphone clipping and tune it for noisy places

[x] Battery power and measured battery life

[x] Currency note and medicine name recognition

[x] Better accent support and more Indian languages

[x] Controlled study with blind and low-vision users

Other:

13. REFERENCES

What to cover:

List every source used in the background research. Use the citation style required by the school. The examples below are possible sources for this project; keep only the sources actually consulted.

Reference 1:

Author / organization: Ultralytics

Year: n.d. (accessed Sept 2026) Title: Object detection

Website / journal / publisher: Ultralytics YOLO Docs

URL or DOI: https://docs.ultralytics.com/tasks/detect/

Reference 2:

Author / organization: Alpha Cephei

Year: n.d. (accessed Sept 2026) Title: Vosk models

Website / journal / publisher: Alpha Cephei

URL or DOI: https://alphacephei.com/vosk/models

Reference 3:

Author / organization: RapidAI

Year: n.d. (accessed Sept 2026) Title: RapidOCR model list

Website / journal / publisher: RapidOCR Docs

URL or DOI: https://rapidai.github.io/RapidOCRDocs/main/model_list/

Reference 4:

Author / organization: Raspberry Pi Ltd

Year: n.d. (accessed Sept 2026) Title: Camera software

Website / journal / publisher: Raspberry Pi Documentation

URL or DOI: https://www.raspberrypi.com/documentation/computers/camera_software.html

Possible technical references to verify and cite if used:

- Redmon, J., Divvala, S., Girshick, R., & Farhadi, A. (2016). You only look once: Unified, real-time object detection. Proceedings of the IEEE Conference on Computer Vision and Pattern Recognition (CVPR).

- Lin, T.-Y., et al. (2014). Microsoft COCO: Common objects in context. European Conference on Computer Vision (ECCV).

- Du, Y., et al. (2020). PP-OCR: A practical ultra lightweight OCR system. arXiv:2009.09941.

- Povey, D., et al. (2011). The Kaldi speech recognition toolkit. IEEE Workshop on Automatic Speech Recognition and Understanding (ASRU).

- World Health Organization. (2019). World report on vision. Geneva: WHO.

- Adafruit. (n.d.). adafruit-circuitpython-vl53l0x. https://pypi.org/project/adafruit-circuitpython-vl53l0x/

- Raspberry Pi Ltd. (n.d.). Device Tree overlays README (googlevoicehat-soundcard). https://github.com/raspberrypi/firmware/blob/master/boot/overlays/README

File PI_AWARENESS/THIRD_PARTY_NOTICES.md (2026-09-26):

# Third-party notices and provenance

The application source in this repository is offered under the included MIT license. Third-party software, models,
OS packages and hardware libraries keep their own licenses. No model weights or OS image are bundled in this ZIP.

| Component | Upstream license / note |
|---|---|
| YOLO26m / optional YOLO26s/n | Review Ultralytics upstream AGPL-3.0/Enterprise terms and the ONNX conversion provenance before redistribution |
| PaddleOCR / RapidOCR models | Apache-2.0 project/model provenance; keep exact downloaded notices |
| Vosk API and selected English/Hindi models | Apache-2.0 labels in the Vosk ecosystem/model catalogue |
| ONNX Runtime | MIT |
| Adafruit CircuitPython VL53L0X | MIT |
| Adafruit Blinka dependencies | Keep exact installed package licenses |
| sounddevice | MIT |
| smbus2 | MIT |
| NumPy | BSD family |
| OpenCV / Picamera2 / libcamera / ALSA | Keep the installed distribution's notices |
| eSpeak NG | GPL; redistribution obligations apply |

The hardware adapter structure is based on the four user-supplied hardware helpers for INMP441, MAX98357A,
VL53L0X and hardware sanity checking. The supplied original hardware check is retained for traceability.

This file is a provenance inventory, not legal advice. Review current licenses for every binary/model included in a distributed image.

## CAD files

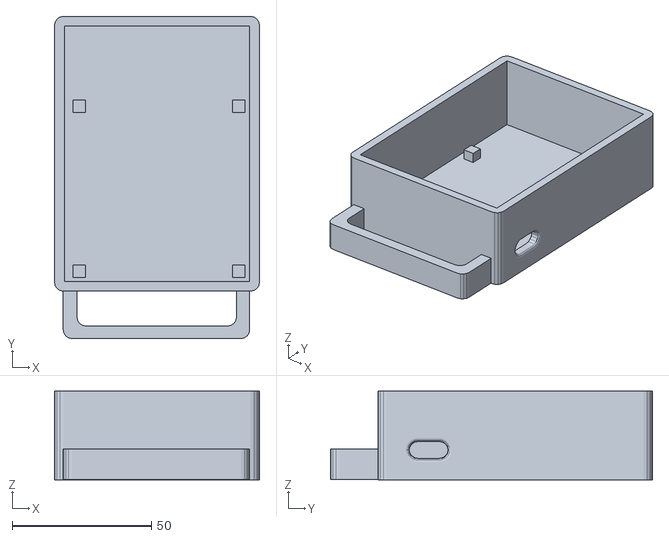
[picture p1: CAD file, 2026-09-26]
Hardware Casing/Box v4.stl
73.5 x 115.5 x 31.8

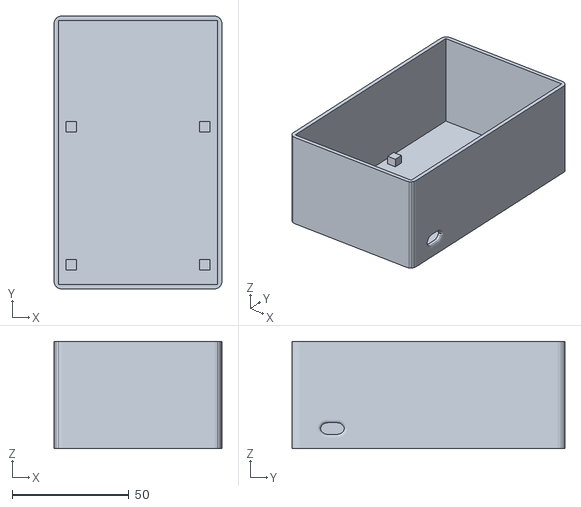
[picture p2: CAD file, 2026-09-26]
Hardware Casing/Box.stl
72.0 x 117.0 x 46.0

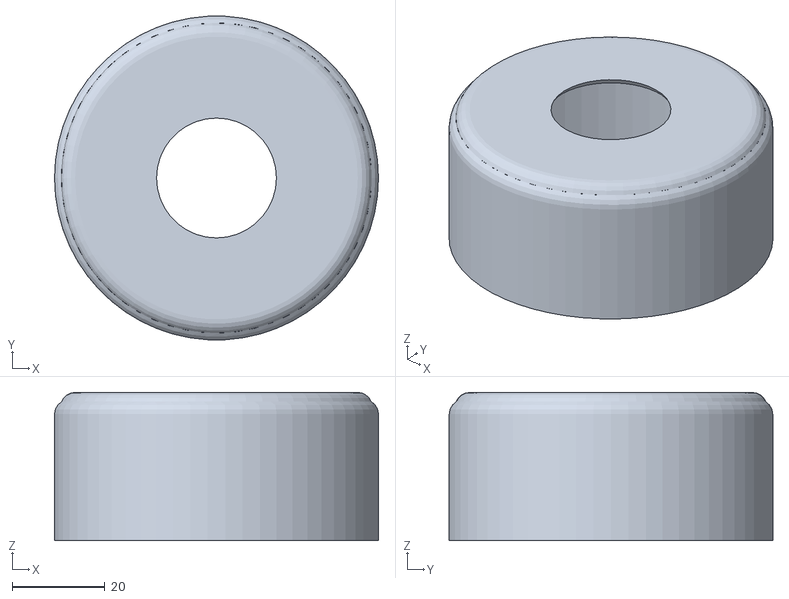
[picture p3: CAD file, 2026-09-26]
Hardware Casing/Speaker Cover.stl
70.0 x 69.9 x 32.0

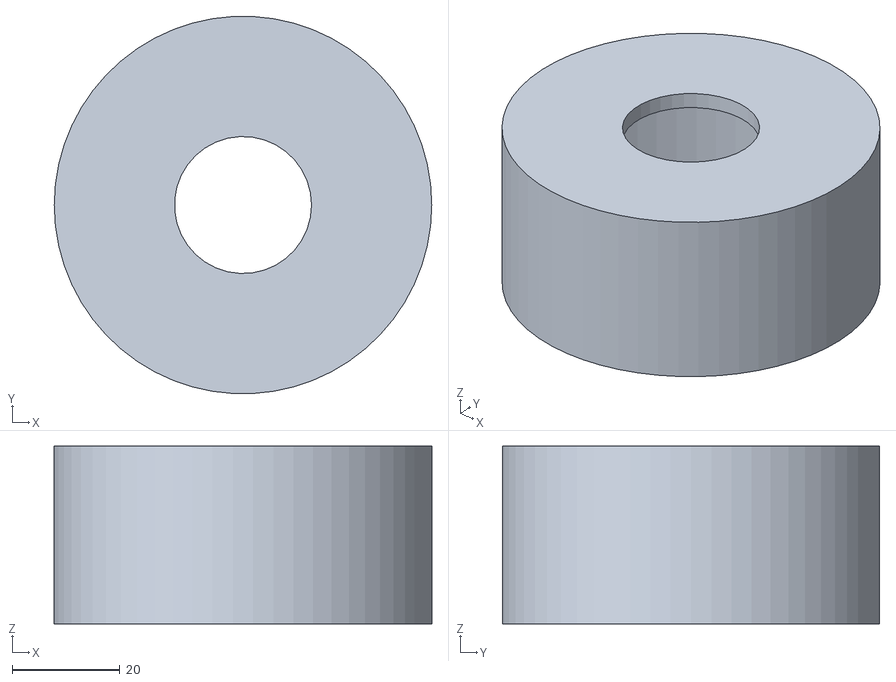
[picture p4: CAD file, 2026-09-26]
Hardware Casing/Speaker Cover v2.stl
70.0 x 69.9 x 33.0

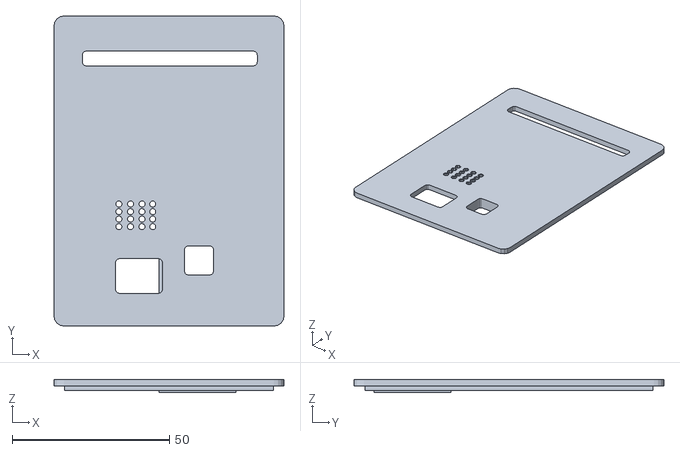
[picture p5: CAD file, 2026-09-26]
Hardware Casing/Top v3.stl
73.0 x 98.4 x 4.00

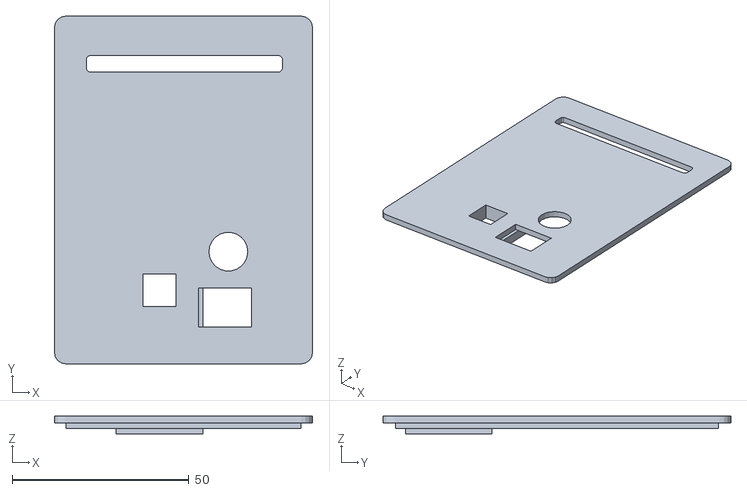
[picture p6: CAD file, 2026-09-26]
Hardware Casing/Top.stl
73.0 x 98.4 x 5.00

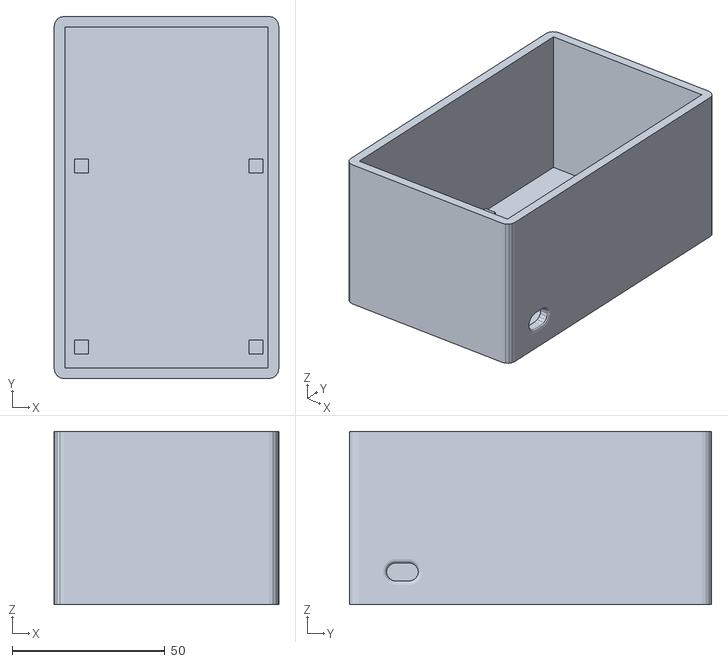
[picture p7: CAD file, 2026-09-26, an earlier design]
Hardware Casing/Box v2.stl
73.5 x 118.5 x 56.8

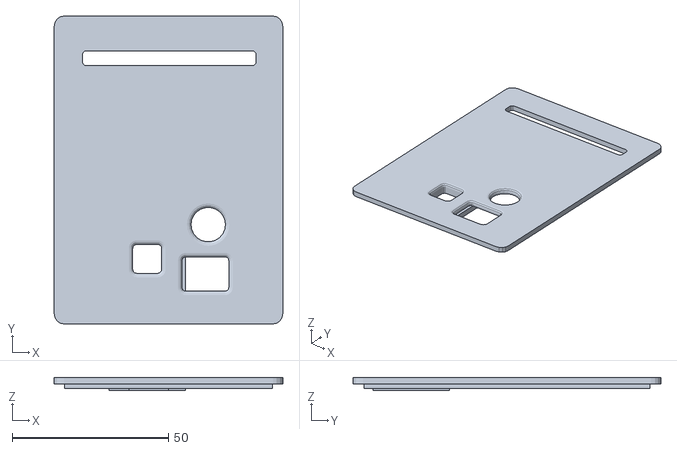
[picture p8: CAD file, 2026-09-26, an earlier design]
Hardware Casing/Top v2.stl
73.0 x 98.4 x 4.00

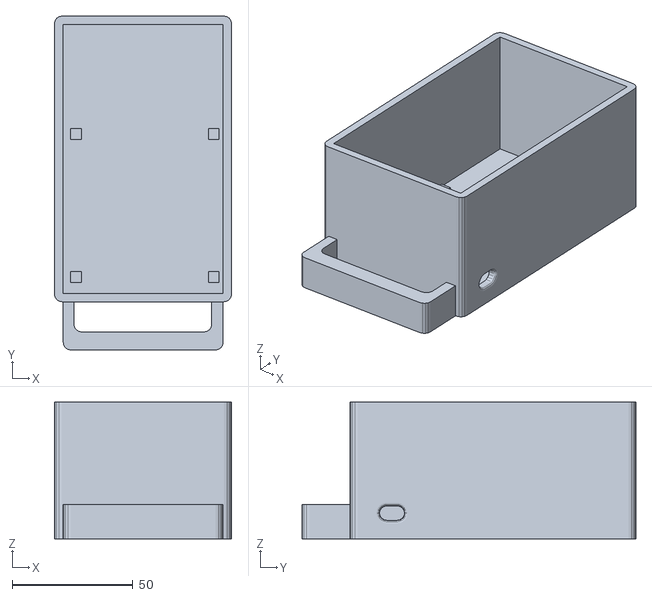
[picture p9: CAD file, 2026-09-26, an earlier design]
Hardware Casing/Box v3.stl
73.5 x 138.5 x 56.8

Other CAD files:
Hardware Casing/OldVersions/Part1.0003.ipt
Hardware Casing/OldVersions/Speaker Cover.0001.ipt
Hardware Casing/Part1.ipt
Hardware Casing/Speaker Cover.ipt
Hardware Casing/Top.ipt

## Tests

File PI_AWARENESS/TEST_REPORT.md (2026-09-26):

# Validation report — PI_AWARENESS 1.2.0 hardware-profile release

Build date: 22 September 2026.

This source release is configured for the user's assembled Raspberry Pi 5 hardware profile:
Raspberry Pi Camera Rev 1.3, INMP441 I2S microphone, MAX98357A I2S amplifier, and VL53L0X.
Model weights are intentionally not bundled; `install.sh` provisions them once.

## Actually executed in the build environment

Environment: Linux x86_64, Python 3.13.5, NumPy 2.3.5, OpenCV 4.13.0.
This machine is **not a Raspberry Pi** and cannot electrically validate the attached hardware.

| Check | Result |
|---|---|
| `python3 server.py --self-test` | **153 tests passed**, 0 failures/errors |
| Compile all Python sources | Passed |
| `bash -n install.sh run.sh tools/install_service.sh` | Passed |
| Exact boot phrase unit test | Passed: `I am ready` is queued before voice capture starts |
| Object-count wording | Passed: repeated detections are counted, including `2 people and 1 chair` |
| On-demand camera path | Passed with mocked Picamera2 backend; close verified |
| INMP441 conversion | Passed with synthetic S32_LE/48 kHz/stereo input to 16 kHz mono PCM |
| VL53L0X on-demand/fail-closed logic | Passed with mocked hardware driver |
| Service profile assertions | Passed: auto-enable, restart-on-failure and private network namespace |
| Config overlay assertions | Passed: I2C, I2S, googlevoicehat sound card, camera auto-detect |
| Existing YOLO26/OCR/voice/software tests | Passed |

The tests cover command parsing in English/Hindi, VAD routing, audio gating, calibration,
object-count descriptions, YOLO26 output decoding, OCR preprocessing/decoding, color processing,
camera lifecycle, offline network blocking, model archive/checksum safety, and error/fail-closed paths.

## Deliberately changed from the previous generic build

- INMP441 is the default microphone backend. It captures S32_LE, 48 kHz, two-channel-framed I2S,
  selects the left channel and converts to 16 kHz signed-16 PCM for Vosk.
- MAX98357A playback auto-resolves the shared `sndrpigooglevoi` ALSA card instead of using a fixed card number.
- Raspberry Pi Camera Rev 1.3 uses Picamera2 and is opened only for `scan`, `color`, or `read`.
- VL53L0X replaces the old VL53L1X path and is read only when the `distance` command is requested.
- Silent idle audio performs RMS/VAD first; Vosk decoding begins only after speech is detected.
- `install.sh` installs/enables `pi-awareness.service`; service starts at boot after the required reboot.
- Successful voice startup speaks exactly `I am ready` once, then enables microphone capture.
- `scan` groups detections by COCO class and speaks counts.

## Not executed / not established here

- Fresh Raspberry Pi OS package installation on a physical Pi 5.
- Device Tree overlay activation and reboot on the user's Pi.
- Real INMP441 electrical capture, analog acoustic sensitivity or final VAD threshold.
- Real MAX98357A playback volume/noise and simultaneous I2S capture/playback behaviour.
- Real Raspberry Pi Camera Rev 1.3 framing/focus/exposure or Picamera2 startup time.
- Real VL53L0X accuracy/range on the assembled device.
- Downloading/loading the actual neural model binaries in this build environment.
- Real YOLO26m, OCR, or Vosk accuracy/latency on the Pi.
- End-of-command to first audible response latency, idle wall power, battery runtime, or enclosure thermals.
- Safety certification or suitability as a sole navigation aid.

Software/mocked tests do not establish the physical results above. After installation and reboot,
run the exact hardware checks in `README.md` and `docs/ACCEPTANCE.md`. In particular, tune
`voice.i2s_gain` and `voice.rms_threshold` from measured quiet/speech values rather than guessing.

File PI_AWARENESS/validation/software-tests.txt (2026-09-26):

test_calibration_cancel (test_app.ApplicationTests.test_calibration_cancel) ... ok
test_calibration_requires_start (test_app.ApplicationTests.test_calibration_requires_start) ... ok
test_camera_failure_spoken_not_faked (test_app.ApplicationTests.test_camera_failure_spoken_not_faked) ... Feature color unavailable: camera failed
Traceback (most recent call last):
  File "/mnt/data/PI_AWARENESS_Pi5_Hardware_v1.2.0/PI_AWARENESS/awareness/app.py", line 169, in process
    result = identify_color(self._frame(), self.cfg.vision)
                            ~~~~~~~~~~~^^
  File "/mnt/data/PI_AWARENESS_Pi5_Hardware_v1.2.0/PI_AWARENESS/awareness/app.py", line 92, in _frame
    raise FeatureError(self.camera_error)
awareness.common.FeatureError: camera failed
ok
test_color_end_to_end_actual_opencv (test_app.ApplicationTests.test_color_end_to_end_actual_opencv) ... ok
test_hindi_auto_locale (test_app.ApplicationTests.test_hindi_auto_locale) ... ok
test_language_switch (test_app.ApplicationTests.test_language_switch) ... ok
test_live_camera_is_on_demand (test_app.ApplicationTests.test_live_camera_is_on_demand) ... ok
test_missing_model_spoken_not_faked (test_app.ApplicationTests.test_missing_model_spoken_not_faked) ... Feature scan unavailable: missing weights
Traceback (most recent call last):
  File "/mnt/data/PI_AWARENESS_Pi5_Hardware_v1.2.0/PI_AWARENESS/awareness/app.py", line 174, in process
    raise FeatureError(self.feature_errors[intent])
awareness.common.FeatureError: missing weights
ok
test_ocr_cancel_drops_late_result (test_app.ApplicationTests.test_ocr_cancel_drops_late_result) ... ok
test_repeat (test_app.ApplicationTests.test_repeat) ... ok
test_sensor_unavailable_no_clear (test_app.ApplicationTests.test_sensor_unavailable_no_clear) ... ok
test_stop_drains_queued_commands (test_app.ApplicationTests.test_stop_drains_queued_commands) ... ok
test_stub_ocr_response (test_app.ApplicationTests.test_stub_ocr_response) ... ok
test_stub_scan_response (test_app.ApplicationTests.test_stub_scan_response) ... ok
test_voice_calibration_requires_confirm (test_app.ApplicationTests.test_voice_calibration_requires_confirm) ... ok
test_voice_start_announces_exact_ready_then_starts_listener (test_app.ApplicationTests.test_voice_start_announces_exact_ready_then_starts_listener) ... ok
test_all_aliases (test_commands_distance.Commands.test_all_aliases) ... ok
test_ambiguous_bilingual_rejected (test_commands_distance.Commands.test_ambiguous_bilingual_rejected) ... ok
test_calibration_english (test_commands_distance.Commands.test_calibration_english) ... ok
test_calibration_hindi (test_commands_distance.Commands.test_calibration_hindi) ... ok
test_clear_bilingual_winner (test_commands_distance.Commands.test_clear_bilingual_winner) ... ok
test_grammar_unk_and_no_digits (test_commands_distance.Commands.test_grammar_unk_and_no_digits) ... ok
test_hindi_marks_preserved (test_commands_distance.Commands.test_hindi_marks_preserved) ... ok
test_low_confidence_rejected (test_commands_distance.Commands.test_low_confidence_rejected) ... ok
test_matching_bilingual_intents (test_commands_distance.Commands.test_matching_bilingual_intents) ... ok
test_no_substring_trigger (test_commands_distance.Commands.test_no_substring_trigger) ... ok
test_punctuation (test_commands_distance.Commands.test_punctuation) ... ok
test_wake_prefix (test_commands_distance.Commands.test_wake_prefix) ... ok
test_close_warning (test_commands_distance.StepDistance.test_close_warning) ... ok
test_conservative_half_steps (test_commands_distance.StepDistance.test_conservative_half_steps) ... ok
test_corrupt_file_falls_back (test_commands_distance.StepDistance.test_corrupt_file_falls_back) ... Invalid calibration; using default: Expecting property name enclosed in double quotes: line 1 column 2 (char 1)
ok
test_default_and_roundtrip (test_commands_distance.StepDistance.test_default_and_roundtrip) ... ok
test_disabled_sensor (test_commands_distance.StepDistance.test_disabled_sensor) ... ok
test_invalid_never_clear (test_commands_distance.StepDistance.test_invalid_never_clear) ... ok
test_invalid_values (test_commands_distance.StepDistance.test_invalid_values) ... ok
test_maximum_cannot_claim_six_steps (test_commands_distance.StepDistance.test_maximum_cannot_claim_six_steps) ... ok
test_measured_walk (test_commands_distance.StepDistance.test_measured_walk) ... ok
test_on_demand_sensor_does_not_reuse_old_cache (test_commands_distance.StepDistance.test_on_demand_sensor_does_not_reuse_old_cache) ... ok
test_three_steps (test_commands_distance.StepDistance.test_three_steps) ... ok
test_walk_bad_counts (test_commands_distance.StepDistance.test_walk_bad_counts) ... ok
test_callback_muted_during_playback (test_hardware_security.AudioTests.test_callback_muted_during_playback) ... ok
test_chunks_preserve_words (test_hardware_security.AudioTests.test_chunks_preserve_words) ... ok
test_i2s_choose_input_is_16k_after_conversion (test_hardware_security.AudioTests.test_i2s_choose_input_is_16k_after_conversion) ... ok
test_i2s_output_auto_resolution (test_hardware_security.AudioTests.test_i2s_output_auto_resolution) ... ok
test_inmp441_s32_stereo_to_16k_mono (test_hardware_security.AudioTests.test_inmp441_s32_stereo_to_16k_mono) ... ok
test_missing_hindi_fails (test_hardware_security.AudioTests.test_missing_hindi_fails) ... ok
test_multilingual_runs (test_hardware_security.AudioTests.test_multilingual_runs) ... ok
test_native_rate_fallback (test_hardware_security.AudioTests.test_native_rate_fallback) ... ok
test_oov_grammar_filtered (test_hardware_security.AudioTests.test_oov_grammar_filtered) ... ok
test_stereo_channel_selection (test_hardware_security.AudioTests.test_stereo_channel_selection) ... ok
test_tts_english_fallback (test_hardware_security.AudioTests.test_tts_english_fallback) ... TTS voice en-in absent; using en
ok
test_capture_once_closes_camera (test_hardware_security.CameraTests.test_capture_once_closes_camera) ... ok
test_fresh_copy (test_hardware_security.CameraTests.test_fresh_copy) ... ok
test_missing_image_never_falls_back (test_hardware_security.CameraTests.test_missing_image_never_falls_back) ... [ WARN:0@0.070] global loadsave.cpp:278 findDecoder imread_('/nonexistent/noimage.png'): can't open/read file: check file path/integrity
ok
test_stale_rejected (test_hardware_security.CameraTests.test_stale_rejected) ... ok
test_install_configures_exact_pi_hardware_overlay (test_hardware_security.DeploymentProfileTests.test_install_configures_exact_pi_hardware_overlay) ... ok
test_service_is_enabled_and_network_isolated (test_hardware_security.DeploymentProfileTests.test_service_is_enabled_and_network_isolated) ... ok
test_archive_size_cap (test_hardware_security.DownloadSecurity.test_archive_size_cap) ... ok
test_local_checksum_verification (test_hardware_security.DownloadSecurity.test_local_checksum_verification) ... ok
test_manifest_pins_and_versions (test_hardware_security.DownloadSecurity.test_manifest_pins_and_versions) ... ok
test_offline_guard_blocks_internet (test_hardware_security.DownloadSecurity.test_offline_guard_blocks_internet) ... ok
test_safe_archive (test_hardware_security.DownloadSecurity.test_safe_archive) ... ok
test_symlink_rejected (test_hardware_security.DownloadSecurity.test_symlink_rejected) ... ok
test_traversal_and_root_rejected (test_hardware_security.DownloadSecurity.test_traversal_and_root_rejected) ... ok
test_no_return_invalid (test_hardware_security.ToFTests.test_no_return_invalid) ... ok
test_on_demand_sensor_uses_nearest_requested_sample (test_hardware_security.ToFTests.test_on_demand_sensor_uses_nearest_requested_sample) ... ok
test_out_of_range_invalid (test_hardware_security.ToFTests.test_out_of_range_invalid) ... ok
test_sensor_failure_is_fail_closed (test_hardware_security.ToFTests.test_sensor_failure_is_fail_closed) ... Distance sensor unavailable: i2c fail
ok
test_valid_mm_preserved (test_hardware_security.ToFTests.test_valid_mm_preserved) ... ok
test_ambiguous_color (test_vision.ColorTests.test_ambiguous_color) ... ok
test_bad_image (test_vision.ColorTests.test_bad_image) ... ok
test_central_region (test_vision.ColorTests.test_central_region) ... ok
test_color_constancy_not_graying_red (test_vision.ColorTests.test_color_constancy_not_graying_red) ... ok
test_darkness_not_false_black (test_vision.ColorTests.test_darkness_not_false_black) ... ok
test_hindi_dark_blue (test_vision.ColorTests.test_hindi_dark_blue) ... ok
test_red_wrap (test_vision.ColorTests.test_red_wrap) ... ok
test_solid_colors (test_vision.ColorTests.test_solid_colors) ... ok
test_crop_and_normalization (test_vision.OCRTests.test_crop_and_normalization) ... ok
test_ctc_dict_mismatch (test_vision.OCRTests.test_ctc_dict_mismatch) ... ok
test_ctc_empty (test_vision.OCRTests.test_ctc_empty) ... ok
test_ctc_nan (test_vision.OCRTests.test_ctc_nan) ... ok
test_ctc_repeat_blank_unicode (test_vision.OCRTests.test_ctc_repeat_blank_unicode) ... ok
test_db_boxes (test_vision.OCRTests.test_db_boxes) ... ok
test_db_low_probability (test_vision.OCRTests.test_db_low_probability) ... ok
test_db_nan (test_vision.OCRTests.test_db_nan) ... ok
test_incomplete_description (test_vision.OCRTests.test_incomplete_description) ... ok
test_order_no_duplicate_corners (test_vision.OCRTests.test_order_no_duplicate_corners) ... ok
test_order_regular_quad (test_vision.OCRTests.test_order_regular_quad) ... ok
test_read_cancel (test_vision.OCRTests.test_read_cancel) ... ok
test_read_cooperative_budget (test_vision.OCRTests.test_read_cooperative_budget) ... ok
test_reading_order (test_vision.OCRTests.test_reading_order) ... ok
test_vertical_crop_rotates (test_vision.OCRTests.test_vertical_crop_rotates) ... ok
test_class_aware_nms (test_vision.ObjectTests.test_class_aware_nms) ... ok
test_description_counts (test_vision.ObjectTests.test_description_counts) ... ok
test_description_not_clear (test_vision.ObjectTests.test_description_not_clear) ... ok
test_description_person_plural (test_vision.ObjectTests.test_description_person_plural) ... ok
test_eighty_classes (test_vision.ObjectTests.test_eighty_classes) ... ok
test_empty_nms (test_vision.ObjectTests.test_empty_nms) ... ok
test_letterbox_distinct (test_vision.ObjectTests.test_letterbox_distinct) ... ok
test_v8_detect_mock_onnx_preprocess (test_vision.ObjectTests.test_v8_detect_mock_onnx_preprocess) ... ok
test_v8_layouts (test_vision.ObjectTests.test_v8_layouts) ... ok
test_v8_wrong_export_rejected (test_vision.ObjectTests.test_v8_wrong_export_rejected) ... ok
test_yolox_detect_mock_onnx_preprocess (test_vision.ObjectTests.test_yolox_detect_mock_onnx_preprocess) ... ok
test_yolox_grid_and_objectness (test_vision.ObjectTests.test_yolox_grid_and_objectness) ... ok
test_yolox_grid_mismatch (test_vision.ObjectTests.test_yolox_grid_mismatch) ... ok
test_export_shape_validation (test_yolo26.ExportUpgradeTests.test_export_shape_validation) ... ok
test_export_static_input_validation (test_yolo26.ExportUpgradeTests.test_export_static_input_validation) ... ok
test_upgrade_idempotent (test_yolo26.ExportUpgradeTests.test_upgrade_idempotent) ... ok
test_upgrade_preserves_unrelated_fields (test_yolo26.ExportUpgradeTests.test_upgrade_preserves_unrelated_fields) ... ok
test_upgrade_unknown_schema_refused (test_yolo26.ExportUpgradeTests.test_upgrade_unknown_schema_refused) ... ok
test_bad_image_rejected (test_yolo26.YOLO26AdapterTests.test_bad_image_rejected) ... ok
test_community_clips_boxes_to_source (test_yolo26.YOLO26AdapterTests.test_community_clips_boxes_to_source) ... ok
test_community_coordinates_and_hindi (test_yolo26.YOLO26AdapterTests.test_community_coordinates_and_hindi) ... ok
test_community_does_not_run_external_nms (test_yolo26.YOLO26AdapterTests.test_community_does_not_run_external_nms) ... ok
test_community_empty_result (test_yolo26.YOLO26AdapterTests.test_community_empty_result) ... ok
test_community_graph_as_native_fails (test_yolo26.YOLO26AdapterTests.test_community_graph_as_native_fails) ... ok
test_community_preprocess_rgb_unit_range_and_no_padding (test_yolo26.YOLO26AdapterTests.test_community_preprocess_rgb_unit_range_and_no_padding) ... ok
test_dedicated_threads (test_yolo26.YOLO26AdapterTests.test_dedicated_threads) ... ok
test_default_is_m640 (test_yolo26.YOLO26AdapterTests.test_default_is_m640) ... ok
test_e2e_native_centered_letterbox_and_remap (test_yolo26.YOLO26AdapterTests.test_e2e_native_centered_letterbox_and_remap) ... ok
test_graph_batch_mismatch_fails (test_yolo26.YOLO26AdapterTests.test_graph_batch_mismatch_fails) ... ok
test_graph_channel_mismatch_fails (test_yolo26.YOLO26AdapterTests.test_graph_channel_mismatch_fails) ... ok
test_graph_size_mismatch_fails (test_yolo26.YOLO26AdapterTests.test_graph_size_mismatch_fails) ... ok
test_invalid_geometry_discarded (test_yolo26.YOLO26AdapterTests.test_invalid_geometry_discarded) ... ok
test_letterbox_rounding_matches_native_export (test_yolo26.YOLO26AdapterTests.test_letterbox_rounding_matches_native_export) ... ok
test_named_community_outputs (test_yolo26.YOLO26AdapterTests.test_named_community_outputs) ... ok
test_native_graph_as_community_fails (test_yolo26.YOLO26AdapterTests.test_native_graph_as_community_fails) ... ok
test_native_raw_runs_nms (test_yolo26.YOLO26AdapterTests.test_native_raw_runs_nms) ... ok
test_timings_reported (test_yolo26.YOLO26AdapterTests.test_timings_reported) ... ok
test_unknown_detector_or_format_rejected (test_yolo26.YOLO26AdapterTests.test_unknown_detector_or_format_rejected) ... ok
test_community_empty_candidates (test_yolo26.YOLO26DecodeTests.test_community_empty_candidates) ... ok
test_community_infinite_box_rejected (test_yolo26.YOLO26DecodeTests.test_community_infinite_box_rejected) ... ok
test_community_infinite_logits_are_sigmoid_limits (test_yolo26.YOLO26DecodeTests.test_community_infinite_logits_are_sigmoid_limits) ... ok
test_community_multi_label_scores_do_not_softmax (test_yolo26.YOLO26DecodeTests.test_community_multi_label_scores_do_not_softmax) ... ok
test_community_nan_logit_rejects_row (test_yolo26.YOLO26DecodeTests.test_community_nan_logit_rejects_row) ... ok
test_community_shapes_rejected (test_yolo26.YOLO26DecodeTests.test_community_shapes_rejected) ... ok
test_community_sigmoid_not_softmax (test_yolo26.YOLO26DecodeTests.test_community_sigmoid_not_softmax) ... ok
test_e2e_empty (test_yolo26.YOLO26DecodeTests.test_e2e_empty) ... ok
test_e2e_invalid_classes_filtered_before_cast (test_yolo26.YOLO26DecodeTests.test_e2e_invalid_classes_filtered_before_cast) ... ok
test_e2e_invalid_scores (test_yolo26.YOLO26DecodeTests.test_e2e_invalid_scores) ... ok
test_e2e_no_input_mutation (test_yolo26.YOLO26DecodeTests.test_e2e_no_input_mutation) ... ok
test_e2e_wrong_contract_rejected (test_yolo26.YOLO26DecodeTests.test_e2e_wrong_contract_rejected) ... ok
test_e2e_xyxy_not_xywh (test_yolo26.YOLO26DecodeTests.test_e2e_xyxy_not_xywh) ... ok
test_all_three_yolo_assets_pinned (test_yolo26.YOLO26ProvisionTests.test_all_three_yolo_assets_pinned) ... ok
test_bad_profile_rejected (test_yolo26.YOLO26ProvisionTests.test_bad_profile_rejected) ... ok
test_benchmark_summary (test_yolo26.YOLO26ProvisionTests.test_benchmark_summary) ... ok
test_conflicting_selection_rejected (test_yolo26.YOLO26ProvisionTests.test_conflicting_selection_rejected) ... ok
test_default_contains_m_not_legacy (test_yolo26.YOLO26ProvisionTests.test_default_contains_m_not_legacy) ... ok
test_missing_verify_never_uses_network (test_yolo26.YOLO26ProvisionTests.test_missing_verify_never_uses_network) ... ok
test_only_detector_and_shared_selection (test_yolo26.YOLO26ProvisionTests.test_only_detector_and_shared_selection) ... ok
test_profile_keeps_other_settings (test_yolo26.YOLO26ProvisionTests.test_profile_keeps_other_settings) ... ok
test_profile_never_changes_thread_policy (test_yolo26.YOLO26ProvisionTests.test_profile_never_changes_thread_policy) ... ok
test_unknown_download_not_silent_fallback (test_yolo26.YOLO26ProvisionTests.test_unknown_download_not_silent_fallback) ... ok

----------------------------------------------------------------------
Ran 153 tests in 0.834s

OK

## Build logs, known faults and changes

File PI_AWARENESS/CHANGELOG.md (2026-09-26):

# Changelog

## 1.2.0 — 22 September 2026

- Rebuilt around the assembled Pi 5 hardware: INMP441, MAX98357A, VL53L0X and Raspberry Pi Camera Rev 1.3.
- Added persistent INMP441 S32_LE/48 kHz I2S capture with DC removal, 48→16 kHz conversion and configurable gain.
- Added automatic shared-I2S ALSA card discovery for both capture and MAX98357A playback.
- Replaced the previous VL53L1X background poller with on-demand VL53L0X measurements.
- Changed CSI camera operation to on-demand capture rather than continuous streaming while idle.
- Added service-first install: `install.sh` configures buses/overlay and enables `pi-awareness.service` automatically.
- Boot/service announcement is exactly `I am ready.` before microphone capture begins.
- `scan` now announces per-class object counts, e.g. `2 people and 1 chair`.
- YOLO26m is optionally warmed once at boot for scan latency; OCR remains lazy by default.
- Added integrated hardware check and INMP441-specific microphone tuning tool.
- Updated tests/docs for the actual hardware profile.

## 1.1.0 — 16 September 2026

- YOLO26m 640×640 became the default detector with YOLO26s/n alternatives.

## 1.0.0

- Initial offline bilingual voice/color/OCR/object/distance prototype.

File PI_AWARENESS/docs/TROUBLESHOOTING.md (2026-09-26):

# Troubleshooting

## Service keeps restarting

```bash
sudo systemctl status pi-awareness
journalctl -u pi-awareness -b -n 200 --no-pager
```

The service intentionally exits/restarts if the voice listener dies.

## I2S card missing

```bash
cat /proc/asound/cards
arecord -l
aplay -l
grep -E 'i2s|googlevoicehat' /boot/firmware/config.txt
```

Expected card name contains `sndrpigooglevoi`. Confirm `dtoverlay=googlevoicehat-soundcard`, then reboot.

## INMP441 is silence

Confirm L/R is tied to GND, VDD is 3.3 V, and GPIO18/19/20 are connected as documented. Stop the service and run:

```bash
.venv/bin/python tools/mic_test.py --seconds 15
```

The software deliberately captures S32_LE/48 kHz. Do not replace that path with direct S16_LE capture for this wiring.

## Speaker silent

MAX98357A VIN should be 5 V, DIN GPIO21/pin 40, and SD must not be held low. Stop the service and run:

```bash
.venv/bin/python tools/speaker_test.py
python -m hardware.max98357a
```

## Camera unavailable

```bash
rpicam-hello --list-cameras
```

If available on your OS, this should show the attached camera. The code uses Picamera2; it does not use the deprecated legacy Picamera stack.
Check the Pi 5 ribbon cable and connector orientation.

## VL53L0X unavailable

```bash
i2cdetect -y 1
```

Expected address is `29`. Confirm SDA/SCL, 3.3 V, ground, and that XSHUT is not low.

## `Device or resource busy`

The `pi-awareness` service normally owns the microphone. Stop it before manual capture or hardware tests:

```bash
sudo systemctl stop pi-awareness
# run test
sudo systemctl start pi-awareness
```

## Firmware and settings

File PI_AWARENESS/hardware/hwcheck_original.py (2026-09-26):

#!/usr/bin/env python3
"""Hardware sanity check for the Gia build on a Raspberry Pi.

Verifies what is actually live right now:
  * the I2C bus comes up and is scannable
  * a device answers at 0x29, and which chip it is
  * whether any ALSA playback/capture cards exist

At this stage the audio lines are *expected* to say "no card" -- the device
tree overlay has not been written yet. That is not a wiring fault.

Usage:
    python3 hwcheck.py            # bus 1 (the 40-pin header)
    python3 hwcheck.py --bus 0    # bus 0, if you are on the CAM/ID pins

Requires:
    pip install smbus2 --break-system-packages
"""

import argparse
import os
import re
import subprocess
import sys

I2C_TARGET = 0x29

# Addresses i2cdetect probes with a read rather than a write-quick, because a
# write to these can latch state on EEPROMs and a few real-time clocks.
READ_PROBE_RANGES = ((0x30, 0x37), (0x50, 0x5F))

CONFIG_PATHS = ("/boot/firmware/config.txt", "/boot/config.txt")


# ---------------------------------------------------------------- output


class Out:
    """Minimal status printer. Colours only when stdout is a terminal."""

    _tty = sys.stdout.isatty()

    @classmethod
    def _c(cls, code, text):
        return f"\033[{code}m{text}\033[0m" if cls._tty else text

    @classmethod
    def section(cls, title):
        print()
        print(cls._c("1", title))
        print(cls._c("2", "-" * len(title)))

    @classmethod
    def ok(cls, msg):
        print(f"  [{cls._c('32', ' ok ')}] {msg}")

    @classmethod
    def warn(cls, msg):
        print(f"  [{cls._c('33', 'warn')}] {msg}")

    @classmethod
    def fail(cls, msg):
        print(f"  [{cls._c('31', 'fail')}] {msg}")

    @classmethod
    def info(cls, msg):
        print(f"  [    ] {msg}")

    @classmethod
    def expected(cls, msg):
        print(f"  [{cls._c('36', 'todo')}] {msg}")


def run(cmd):
    """Run a command, returning (rc, stdout+stderr). rc 127 if not installed."""
    try:
        p = subprocess.run(cmd, capture_output=True, text=True, timeout=10)
        return p.returncode, (p.stdout or "") + (p.stderr or "")
    except FileNotFoundError:
        return 127, ""
    except subprocess.TimeoutExpired:
        return 124, ""


# ---------------------------------------------------------------- platform


def check_platform():
    Out.section("Platform")

    model = "unknown"
    try:
        with open("/proc/device-tree/model") as fh:
            model = fh.read().strip("\x00").strip()
    except OSError:
        pass

    if "Raspberry Pi" in model:
        Out.ok(model)
    else:
        Out.warn(f"not a Raspberry Pi? /proc/device-tree/model reports: {model}")

    Out.info(f"python {sys.version.split()[0]}")

    for path in CONFIG_PATHS:
        if not os.path.exists(path):
            continue
        try:
            with open(path) as fh:
                text = fh.read()
        except OSError as exc:
            Out.warn(f"{path}: {exc}")
            break

        live = [
            ln.strip()
            for ln in text.splitlines()
            if ln.strip() and not ln.strip().startswith("#")
        ]
        if any(re.match(r"dtparam=i2c_arm=on\b", ln) for ln in live):
            Out.ok(f"dtparam=i2c_arm=on present in {path}")
        else:
            Out.fail(f"dtparam=i2c_arm=on NOT active in {path} -- add it and reboot")

        overlays = [ln for ln in live if ln.startswith("dtoverlay=")]
        if overlays:
            Out.info("overlays loaded from config.txt: " + ", ".join(overlays))
        else:
            Out.expected("no dtoverlay= lines yet (expected -- audio overlay comes next)")
        break
    else:
        Out.warn("no config.txt found at either /boot/firmware or /boot")


# ---------------------------------------------------------------- i2c bus


def check_bus_node(bus):
    Out.section(f"I2C bus {bus}")

    node = f"/dev/i2c-{bus}"
    if not os.path.exists(node):
        Out.fail(f"{node} does not exist")
        Out.info("the kernel has no I2C adapter -- causes, most likely first:")
        Out.info("  1. dtparam=i2c_arm=on missing from config.txt (then reboot)")
        Out.info("  2. i2c-dev module not loaded: sudo modprobe i2c-dev")
        return False

    Out.ok(f"{node} present")
    if not os.access(node, os.R_OK | os.W_OK):
        Out.fail(f"no read/write access to {node}")
        Out.info("add yourself to the i2c group: sudo usermod -aG i2c $USER, then log out and back in")
        return False

    Out.ok("read/write access confirmed")
    return True


def scan_bus(smbus, bus):
    """Return the sorted list of addresses that acknowledge on the bus."""
    found = []
    try:
        with smbus.SMBus(bus) as sm:
            for addr in range(0x03, 0x78):
                use_read = any(lo <= addr <= hi for lo, hi in READ_PROBE_RANGES)
                try:
                    if use_read:
                        sm.read_byte(addr)
                    else:
                        sm.write_quick(addr)
                    found.append(addr)
                except OSError:
                    continue
    except (OSError, PermissionError) as exc:
        Out.fail(f"could not open bus {bus}: {exc}")
        return None
    return found


def report_scan(found):
    if found is None:
        return

    if not found:
        Out.fail("bus scanned clean -- no devices acknowledged at any address")
        Out.info("likely causes, in order:")
        Out.info("  1. the fifth pin on the clone board is holding the chip in reset")
        Out.info("     (XSHUT / GPIO0 -- tie it high to 3V3, or drive it high)")
        Out.info("  2. SDA and SCL swapped -- easy on that board, the silkscreen")
        Out.info("     runs SCL before SDA, the reverse of the Pi header order")
        Out.info("  3. dtparam=i2c_arm=on missing from config.txt")
        Out.info("  4. no pull-ups / unpowered board -- check 3V3 and GND first")
        return

    Out.ok(f"{len(found)} device(s) responding: " + ", ".join(f"0x{a:02x}" for a in found))
    if I2C_TARGET in found:
        Out.ok(f"0x{I2C_TARGET:02x} present -- this is the one we want")
    else:
        Out.fail(f"nothing at 0x{I2C_TARGET:02x}")
        Out.info("something is on the bus, so wiring and pull-ups are fine;")
        Out.info("the board is answering on a different address than expected")


# ---------------------------------------------------------------- chip id

# Everything that commonly sits at 0x29, and how to tell it apart.
# Each probe: (name, reader, expected-values, library to install)
#
# VL53L0X  reg 0xC0 (8-bit)    -> 0xEE
# VL53L1X  reg 0x010F (16-bit) -> 0xEA 0xCC
# TSL2591  reg 0x12 | 0xA0     -> 0x50
# TCS34725 reg 0x12 | 0x80     -> 0x44 / 0x4D / 0x10


def _r8(sm, addr, reg):
    return sm.read_byte_data(addr, reg)


def _r16reg(sm, addr, reg16):
    """Read one byte from a 16-bit register address (ST ToF style)."""
    from smbus2 import i2c_msg

    write = i2c_msg.write(addr, [(reg16 >> 8) & 0xFF, reg16 & 0xFF])
    read = i2c_msg.read(addr, 2)
    sm.i2c_rdwr(write, read)
    return list(read)


def identify_chip(smbus, bus):
    Out.section(f"Chip identification at 0x{I2C_TARGET:02x}")

    results = []
    try:
        with smbus.SMBus(bus) as sm:
            # VL53L1X -- 16-bit register space, model id 0xEACC
            try:
                data = _r16reg(sm, I2C_TARGET, 0x010F)
                results.append(("VL53L1X model id 0x010F", f"0x{data[0]:02x}{data[1]:02x}"))
                if data[0] == 0xEA and data[1] == 0xCC:
                    Out.ok("VL53L1X time-of-flight ranger (model id 0xEACC)")
                    Out.info("install: pip install VL53L1X --break-system-packages")
                    return "VL53L1X"
            except OSError:
                pass

            # VL53L0X -- 8-bit register space, model id 0xEE
            try:
                model = _r8(sm, I2C_TARGET, 0xC0)
                rev = _r8(sm, I2C_TARGET, 0xC2)
                results.append(("VL53L0X model id 0xC0", f"0x{model:02x}"))
                if model == 0xEE:
                    Out.ok(f"VL53L0X time-of-flight ranger (model 0xEE, rev 0x{rev:02x})")
                    Out.info("install: pip install adafruit-circuitpython-vl53l0x --break-system-packages")
                    return "VL53L0X"
            except OSError:
                pass

            # TSL2591 -- command bit 0xA0, ID 0x50
            try:
                ident = _r8(sm, I2C_TARGET, 0xA0 | 0x12)
                results.append(("TSL2591 id 0xB2", f"0x{ident:02x}"))
                if ident == 0x50:
                    Out.ok("TSL2591 ambient light sensor (id 0x50)")
                    Out.info("install: pip install adafruit-circuitpython-tsl2591 --break-system-packages")
                    return "TSL2591"
            except OSError:
                pass

            # TCS34725 -- command bit 0x80, ID 0x44 / 0x4D / 0x10
            try:
                ident = _r8(sm, I2C_TARGET, 0x80 | 0x12)
                results.append(("TCS34725 id 0x92", f"0x{ident:02x}"))
                if ident in (0x44, 0x4D, 0x10):
                    Out.ok(f"TCS34725 colour sensor (id 0x{ident:02x})")
                    Out.info("install: pip install adafruit-circuitpython-tcs34725 --break-system-packages")
                    return "TCS34725"
            except OSError:
                pass

    except (OSError, PermissionError) as exc:
        Out.fail(f"could not open bus {bus} for identification: {exc}")
        return None

    Out.warn("device answers, but no known chip signature matched")
    if results:
        Out.info("raw register reads, for the record:")
        for label, value in results:
            Out.info(f"    {label} = {value}")
    else:
        Out.info("every identification register read failed -- the device ACKs its")
        Out.info("address but will not serve registers. Often a chip still held in")
        Out.info("reset, or a clone with a non-standard register map.")
    return None


# ---------------------------------------------------------------- audio


def check_audio():
    Out.section("Audio")

    cards_path = "/proc/asound/cards"
    have_cards = False
    if os.path.exists(cards_path):
        try:
            with open(cards_path) as fh:
                text = fh.read()
            have_cards = "no soundcards" not in text.lower() and text.strip() != ""
        except OSError:
            pass

    for label, cmd in (("playback", ["aplay", "-l"]), ("capture", ["arecord", "-l"])):
        rc, out = run(cmd)
        if rc == 127:
            Out.warn(f"{label}: alsa-utils not installed (sudo apt install alsa-utils)")
            continue

        names = [ln.strip() for ln in out.splitlines() if ln.startswith("card ")]
        # The Pi 5's two HDMI outputs are always present and are not our I2S bus.
        ours = [n for n in names if "vc4hdmi" not in n]

        if not names or "no soundcards" in out.lower():
            Out.expected(f"{label}: no card -- correct for now, the overlay is not written yet")
            continue

        for name in names:
            Out.info(f"    {name}")
        if ours:
            Out.ok(f"{label}: I2S card present -- {len(ours)} of {len(names)}")
        else:
            Out.expected(
                f"{label}: {len(names)} card(s), all HDMI -- no I2S card yet, overlay not written"
            )

    if not have_cards:
        Out.expected("/proc/asound reports no soundcards -- expected at this stage")


# ---------------------------------------------------------------- main


def main():
    ap = argparse.ArgumentParser(description="Gia hardware sanity check")
    ap.add_argument("--bus", type=int, default=1, help="I2C bus number (default: 1)")
    args = ap.parse_args()

    print("Gia hardware check")
    print("==================")

    check_platform()

    try:
        import smbus2 as smbus
    except ImportError:
        Out.section(f"I2C bus {args.bus}")
        Out.fail("smbus2 not installed")
        Out.info("install it with: pip install smbus2 --break-system-packages")
        check_audio()
        print()
        return 1

    if check_bus_node(args.bus):
        found = scan_bus(smbus, args.bus)
        report_scan(found)
        if found and I2C_TARGET in found:
            identify_chip(smbus, args.bus)

    check_audio()

    print()
    print("Next: post this output and we will write the device tree overlay.")
    print()
    return 0


if __name__ == "__main__":
    sys.exit(main())

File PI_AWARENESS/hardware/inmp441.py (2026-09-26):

#!/usr/bin/env python3
"""INMP441 microphone adapter for the assembled Pi 5.

Wiring from the supplied hardware test:
  SCK/BCLK -> physical pin 12 (GPIO18)
  WS/LRCLK -> physical pin 35 (GPIO19)
  SD/DOUT  -> physical pin 38 (GPIO20)
  VDD      -> 3V3
  GND      -> GND
  L/R      -> GND (left channel)

The microphone supplies 24-bit data in 32-bit I2S frames.  We therefore keep
ALSA at S32_LE/48 kHz stereo and perform the small 48 -> 16 kHz conversion in
Python.  Asking this wiring/overlay for S16_LE directly can produce unusable
capture on this setup.
"""
from __future__ import annotations
import subprocess
import threading
import time
import wave
from pathlib import Path
import numpy as np
from .i2s_common import find_i2s_device

RATE = 48000
CHANNELS = 2
CHANNEL_INDEX = 0
FULL_SCALE = float(2**31)


def _read_exact(stream, count: int) -> bytes:
    chunks = bytearray()
    while len(chunks) < count:
        part = stream.read(count - len(chunks))
        if not part:
            break
        chunks.extend(part)
    return bytes(chunks)


def convert_i2s_block(raw: bytes, *, channel_index: int = CHANNEL_INDEX,
                      input_rate: int = RATE, output_rate: int = 16000,
                      gain: float = 10.0) -> bytes:
    """Convert one S32_LE stereo block to mono signed-16 PCM.

    A per-block DC removal mirrors the behaviour of the supplied standalone
    microphone helper.  A 3-sample box average provides a lightweight speech
    low-pass while converting 48 kHz to 16 kHz.  Gain is fixed/configurable;
    we intentionally do not normalize every silent block because that would
    amplify background noise into false voice activity.
    """
    if not raw:
        return b""
    data = np.frombuffer(raw, dtype="<i4")
    usable = (data.size // CHANNELS) * CHANNELS
    if usable == 0:
        return b""
    stereo = data[:usable].reshape(-1, CHANNELS)
    if channel_index < 0 or channel_index >= CHANNELS:
        raise ValueError("INMP441 channel index must be 0 or 1")
    mono = stereo[:, channel_index].astype(np.float64)
    if mono.size == 0:
        return b""
    mono -= mono.mean()
    if input_rate % output_rate:
        raise ValueError("INMP441 lightweight converter requires an integer rate ratio")
    step = input_rate // output_rate
    usable = (mono.size // step) * step
    if usable == 0:
        return b""
    mono = mono[:usable].reshape(-1, step).mean(axis=1)
    scaled = np.clip((mono / FULL_SCALE) * gain * 32767.0, -32768, 32767)
    return scaled.astype("<i2").tobytes()


class INMP441Stream:
    """Persistent low-overhead ALSA capture used by the always-listening VAD."""
    def __init__(self, *, device: str | None = None, block_ms: int = 50,
                 output_rate: int = 16000, channel_index: int = 0,
                 gain: float = 10.0, on_block=None, on_error=None):
        self.device = device or find_i2s_device()
        self.block_ms = int(block_ms)
        self.output_rate = int(output_rate)
        self.channel_index = int(channel_index)
        self.gain = float(gain)
        self.on_block = on_block
        self.on_error = on_error
        self.process: subprocess.Popen | None = None
        self.thread: threading.Thread | None = None
        self.done = threading.Event()
        self.error = ""
        frames = max(1, int(RATE * self.block_ms / 1000))
        self.raw_block_bytes = frames * CHANNELS * 4

    def start(self):
        if self.process is not None:
            return self
        cmd = [
            "arecord", "-q", "-D", self.device,
            "-f", "S32_LE", "-r", str(RATE), "-c", str(CHANNELS),
            "-t", "raw",
        ]
        self.process = subprocess.Popen(
            cmd, stdout=subprocess.PIPE, stderr=subprocess.PIPE, bufsize=0
        )
        self.thread = threading.Thread(target=self._run, name="inmp441", daemon=True)
        self.thread.start()
        return self

    def _run(self):
        assert self.process is not None and self.process.stdout is not None
        try:
            while not self.done.is_set():
                raw = _read_exact(self.process.stdout, self.raw_block_bytes)
                if len(raw) != self.raw_block_bytes:
                    if self.done.is_set():
                        break
                    stderr = b""
                    if self.process.stderr is not None:
                        try:
                            stderr = self.process.stderr.read(512)
                        except Exception:
                            pass
                    raise RuntimeError(
                        "INMP441 arecord stopped unexpectedly: "
                        + stderr.decode("utf-8", errors="replace").strip()
                    )
                pcm = convert_i2s_block(
                    raw, channel_index=self.channel_index,
                    output_rate=self.output_rate, gain=self.gain,
                )
                if pcm and self.on_block:
                    self.on_block(time.monotonic(), pcm)
        except Exception as exc:
            self.error = str(exc)
            if self.on_error and not self.done.is_set():
                self.on_error(exc)
        finally:
            self._terminate()

    def _terminate(self):
        proc = self.process
        if proc is None:
            return
        if proc.poll() is None:
            proc.terminate()
            try:
                proc.wait(timeout=1.5)
            except subprocess.TimeoutExpired:
                proc.kill()
                proc.wait(timeout=1.5)

    def close(self):
        self.done.set()
        self._terminate()
        if self.thread and self.thread.is_alive():
            self.thread.join(timeout=2)
        self.process = None
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
